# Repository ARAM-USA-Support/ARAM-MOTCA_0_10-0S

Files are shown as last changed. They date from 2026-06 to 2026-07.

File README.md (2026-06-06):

Welcome to the ARAM-MOTCA_0_10-0S documentation mirror.

Read the spec sheet to understand the electrical characteristics of your actuator

View the Quick Start Guide to become familar with how to use your actuator

Example code is provided here, in addition to the code provided within the guide

For those wishing to make their own, they can follow the manufacture guide in the Project File & Technical Data Package.
This is a self contianed zip file, which contains the stl files and assembly guide, along with all the information here.

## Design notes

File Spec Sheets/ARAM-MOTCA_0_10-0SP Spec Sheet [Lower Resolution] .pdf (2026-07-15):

American Robotics Assisted Manufacturing | Rev 6/28/2026

# Metal Orchestra Toggle Actuator

# ARAM-MOTCA_0_11-0SP*

### 0SPG (Pet-g) and 0SPA (PLA) variants

# Spec Sheet

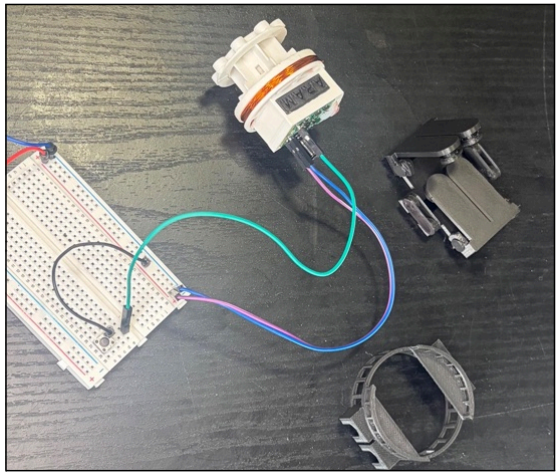
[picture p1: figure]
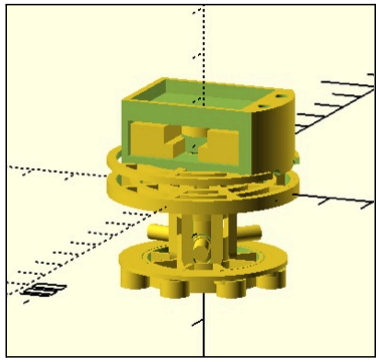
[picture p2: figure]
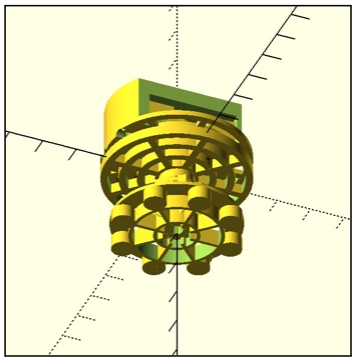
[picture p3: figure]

## Product of American Robotics Assisted Manufacturing www.ARAM-USA.com

## ARAM-MOTCA_0_10-0SP* Spec Sheet

## View further kit usage information & legal information

# Table Of Contents

Overview | 1
Quick Facts - Electrical & Force Characteristics | 2
Pinout Diagram - Basic Operation | 3
Physical And Mechanical Data | 4
Operating Conditions & Limitations | 5

# Overview

This mini actuator is part of the ARAM Metal Orchestra set.

# These are smart actuators utilizing an integrated high efficiency

h-bridge, with simplified control schema requiring only a single pin.

# The actuator integrates a magnetic attaching base to allow these to

attach to any magnetic object.

# These are intended for use as part of the Metal Orchestra kit that allows users to turn household objects into an orchestra. However these have tons of additional applications, including unique I/O

devices, animatronics, smart-home integration and more.

*Please read the usage guide and view legal disclaimers.

# Quick Facts:

# Electrical Characteristics

Continuous Voltage Range | 3.3V - 5V | Over-Voltage* Range | 5.1V - 12V
Average 5V Current Draw | 0.35 - 0.46 Amps | H-Bridge (Driver) Resistance | 0.2 ohms
Total Component Resistance | 11.2 - 13.2 ohms | Solenoid Resistance | 11 - 13 ohms
Input Voltage | 1.8V * (Reduced Efficiency), 3.3V, and 5V

*Actuator may run continuously at or below 5V, above this the Over-Voltage range (5.1V - 12V) is electrically acceptable for the driver to handle, however this will cause the armature to heat up, causing damage over time if not properly cooled.

*1.8 Volts will work for logic, However this has reduced efficiency (greater effective resistance) and will possibly reduce the working life.

# Force Characteristics

| 3.3V | 5V
Strike Time | 50 ms | 20 ms
Force (Average Over Strike) | 0.09 N | 0.22 N
Plunger Weight | 7g
Force of Gravity on Plunger | 0.068 N
Travel Distance | 4.5mm +/- 0.15 mm

### *Force may be limited by magnetic interference

### Material Options: Pet-G, PLA

# Pinout and Basic Usage

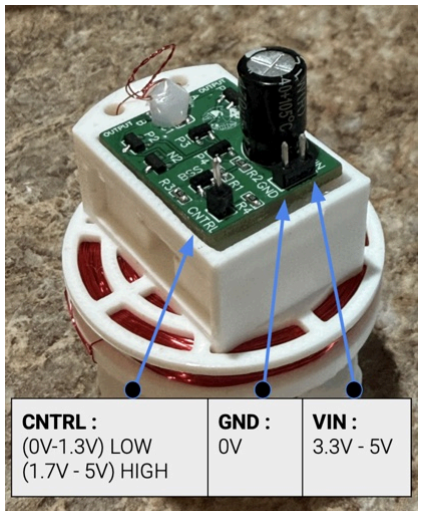
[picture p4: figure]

Pin | Voltage | Additional Comments
VIN | 3.3V to 5V Continuous 5V+ to 12V Pulsed | Incorrectly plugging VIN to 0V may damage your unit
GND | 0V | Incorrectly plugging GND to voltage may damage your unit
CNTRL | (0V - 1.3V) Low (1.7V - 5V) High | (Default) Pulldown to 0V High Signal will cause strike Low Signal will cause retract

# Physical And Mechanical Data

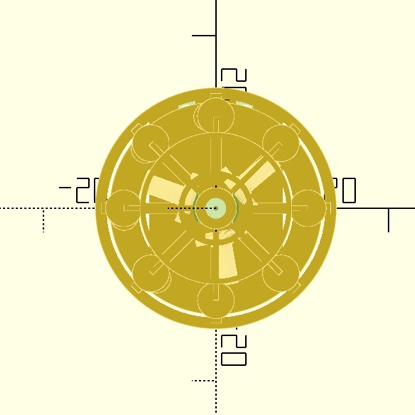
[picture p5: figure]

## Dimensions:

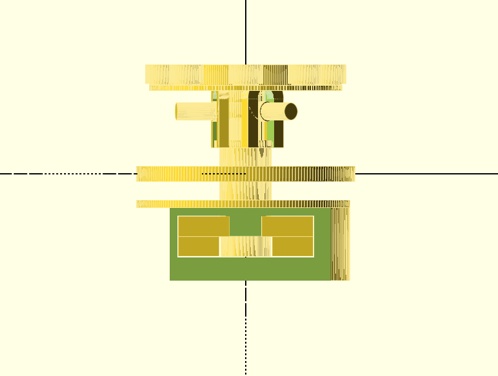
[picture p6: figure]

Height | ~58mm
Diameter | ~40mm

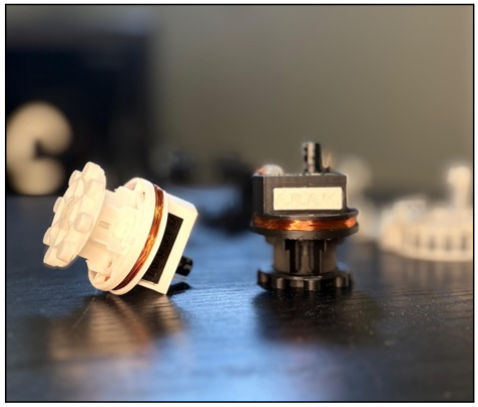
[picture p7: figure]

## Weight: About 42 grams (fully assembled)

## Mounting Options: Magnetic Feet

## Materials: ARAM-MOTCA_0_10-0SPG : Pet-G ARAM-MOTCA_0_10-0SPA : PLA

# Operating Conditions & Limitations

## Maximum Continuous Temperature : 49 degrees celsius *Prolonged temperatures above this range will cause armature housing to deform, especially under weight

## Environmental Notes : Not guaranteed to be dust or water resistant

## Reverse Polarity : failing to follow pin-out and switching the power supply polarity will damage the unit, doing so for a long enough time, with a large

enough power supply can be a potential fire hazard.

## Magnetic Interference : This device produces a magnetic field, be aware of

any damage that may be caused to sensitive electronics, pace makers, etc.

## Troubleshooting: The actuator works most of the time, but when I place it in this specific spot it stops working: The actuator is sensitive to magnetic interference, metal extremely close to the armature tube can cause a loss in power of the device. Either move the

device away from interfering metal, or increase the supply voltage.

## Additional Resources: https://github.com/ARAM-USA-Support/ARAM-MOTCA_0_10-0S (MOTCA-1 Toggle Actuator Github Documentation Mirror) *All documentation is also available at www.ARAM-USA.com

## For any additional troubleshooting or questions please: View Our Website : www.ARAM-USA.com Contact Us At: support@ARAM-USA.com

DISCLAIMER. – ALL PRODUCTS SOLD BY ARAM (AMERICAN ROBOTICS ASSISTED MANUFACTURING) ARE PROVIDED “AS IS” TO THE FULLEST EXTENT PERMITTED BY APPLICABLE LAW, ARAM EXPRESSLY DISCLAIMS ALL WARRANTIES, EXPRESS OR IMPLIED, INCLUDING BUT NOT LIMITED TO THE IMPLIED WARRANTIES OF MERCHANTABILITY, FITNESS FOR A PARTICULAR PURPOSE, AND NON-INFRINGEMENT. ARAM MAKES NO WARRANTY THAT THE PRODUCT WILL MEET YOUR SPECIFIC REQUIREMENTS OR THAT IT WILL OPERATE WITHOUT INTERRUPTION OR ERROR. All units are tested prior to sale; however, ARAM does not warrant that every unit will arrive in working condition. Electrical properties and specifications provided in this document are for reference purposes only. It is the sole responsibility of the user to verify that the specifications provided herein match the electrical characteristics of the unit received. Use of this product outside of stated operating parameters is at the user’s own risk.

Sole Remedy – Replacement Only. ARAM takes no responsibility for any damages caused by the use of our product, whether inside or outside standard operating conditions. In the event of a defect or failure, ARAM’s sole obligation, and your exclusive remedy, shall be the replacement of the defective unit within thirty (30) days of the original purchase date. To qualify for replacement, the buyer must contact ARAM within this period and is responsible for all shipping and handling costs associated with the return and replacement.

Limitation of Liability. TO THE MAXIMUM EXTENT PERMITTED BY APPLICABLE LAW, IN NO EVENT SHALL ARAM BE LIABLE FOR ANY INDIRECT, INCIDENTAL, SPECIAL, CONSEQUENTIAL, OR PUNITIVE DAMAGES OF ANY KIND ARISING OUT OF OR RELATED TO THE USE OR INABILITY TO USE THIS PRODUCT. ARAM’S TOTAL CUMULATIVE LIABILITY TO YOU FOR ANY AND ALL CLAIMS ARISING OUT OF OR RELATED TO THIS PRODUCT SHALL NOT EXCEED THE ORIGINAL PURCHASE PRICE PAID FOR THE SPECIFIC UNIT GIVING RISE TO THE CLAIM. THIS LIMITATION OF LIABILITY SHALL APPLY EVEN IF THE SOLE AND EXCLUSIVE REMEDY PROVIDED HEREIN IS FOUND TO HAVE FAILED OF ITS ESSENTIAL PURPOSE, AND SHALL APPLY WHETHER THE CLAIM IS BASED IN CONTRACT, TORT, STRICT LIABILITY, OR ANY OTHER LEGAL THEORY.

Important Note. Some states, including New York, may have consumer protection laws that limit the enforceability of certain warranty disclaimers. Nothing in this disclaimer is intended to exclude or restrict any rights you may have under applicable state law that cannot be waived by contract.

# Thank you for purchasing an ARAM product

## We would like to thank you for purchasing an ARAM product. We highly value customers like you. If you have any feedback, suggestions, or questions, please reach out to our contact

email. If your unit arrives with any issues please contact us within 30 days for a replacement. We would like to thank you for supporting ARAM, American Robotics Assisted Manufacturing, a 100% American based work force and company.

## Sincerely:

Jack Serlin,

## Founder of American Robotics Assisted Manufacturing

## Contact Email: Support@Aram-usa.com

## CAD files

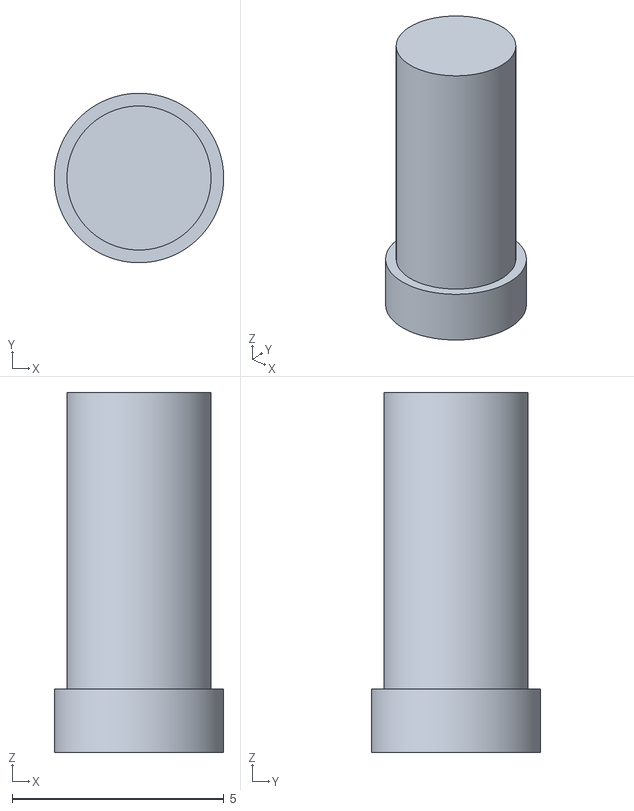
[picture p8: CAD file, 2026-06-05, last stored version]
STL files/MOTCA_1_Plunger_Pin.stl
4.00 x 4.00 x 8.50

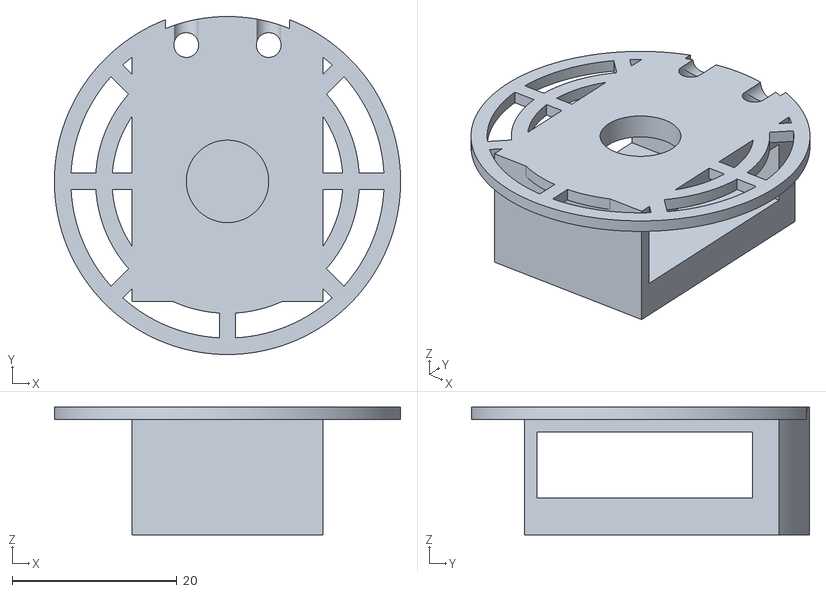
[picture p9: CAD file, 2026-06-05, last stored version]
STL files/MOTCA_1_Armature_Upper.stl
42.0 x 41.0 x 15.5

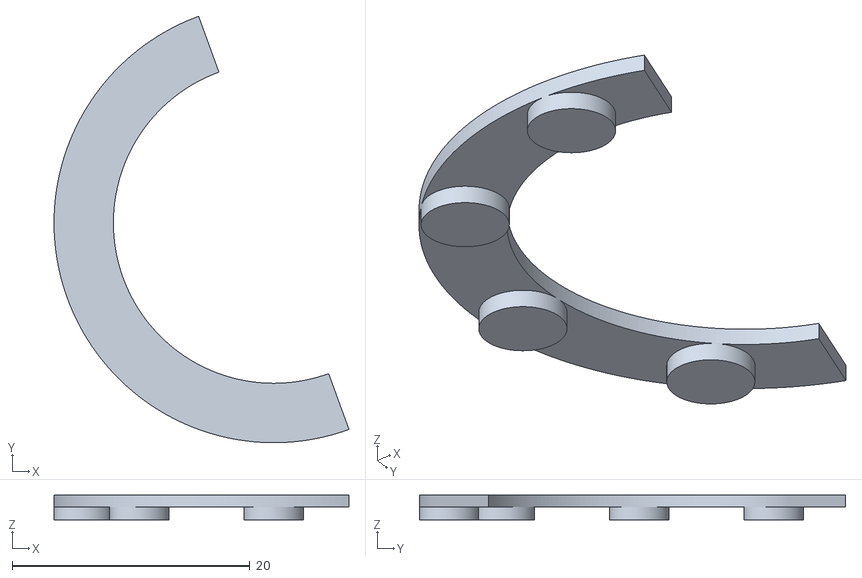
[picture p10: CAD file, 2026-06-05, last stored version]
STL files/MOTCA_1_Armature_Magnetic_Feet_Cover.stl
24.8 x 35.9 x 2.08

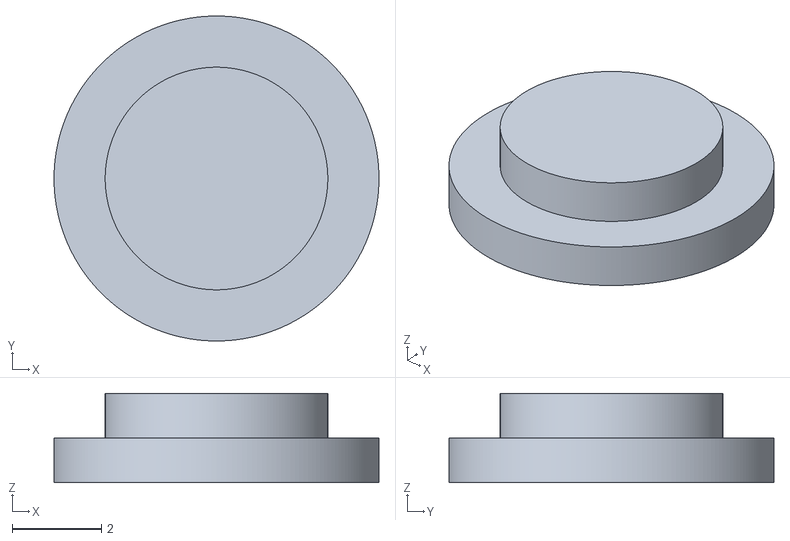
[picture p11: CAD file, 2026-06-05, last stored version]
STL files/MOTCA_1_Plunger_Cap.stl
7.30 x 7.30 x 2.00

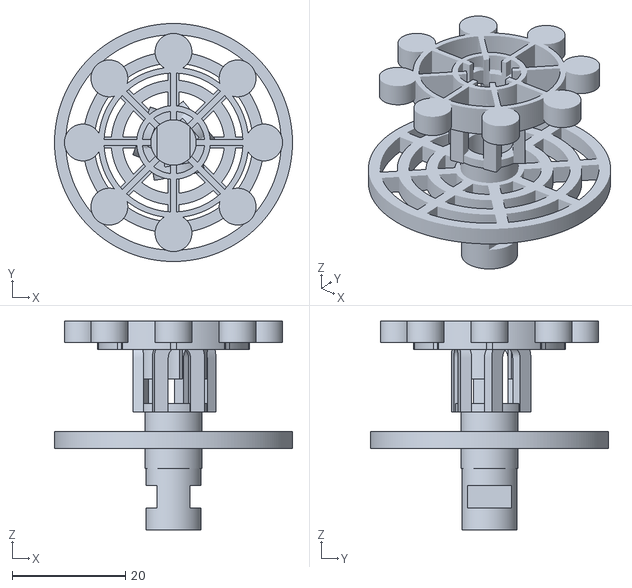
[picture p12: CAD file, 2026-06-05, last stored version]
STL files/MOTCA_1_Armature_Lower.stl
42.0 x 42.0 x 36.8

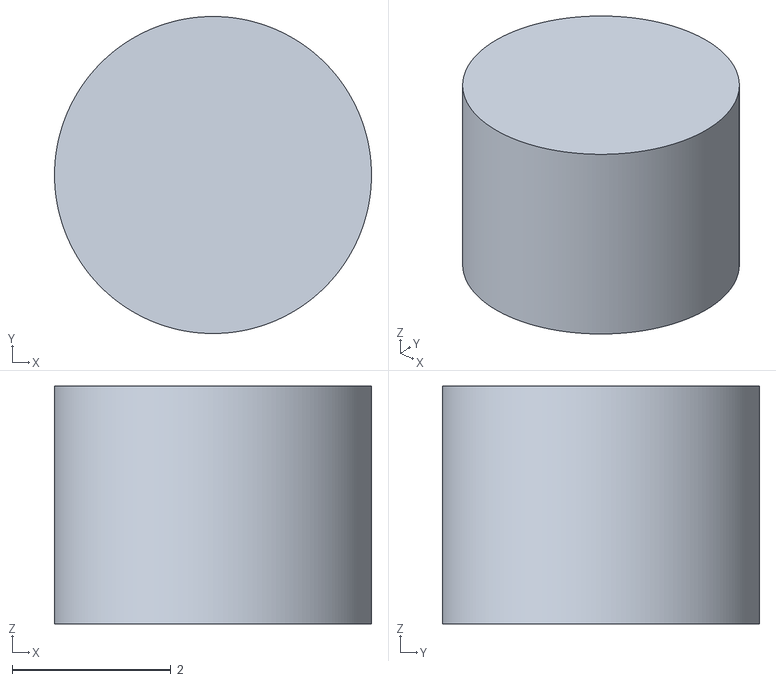
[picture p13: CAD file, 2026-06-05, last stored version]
STL files/bipositional_actuator_v3BasePin.stl
4.00 x 4.00 x 3.00

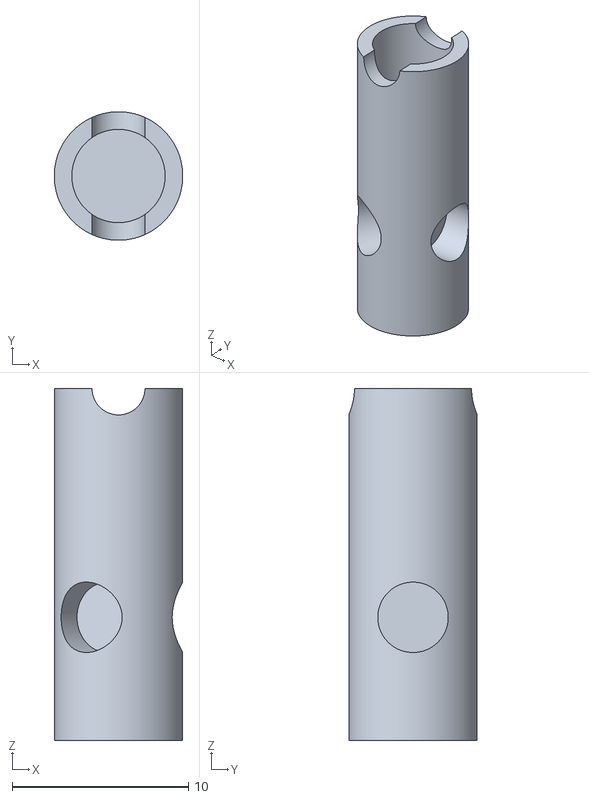
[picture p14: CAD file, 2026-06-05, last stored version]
STL files/MOTCA_1_Plunger.stl
7.30 x 7.30 x 20.0

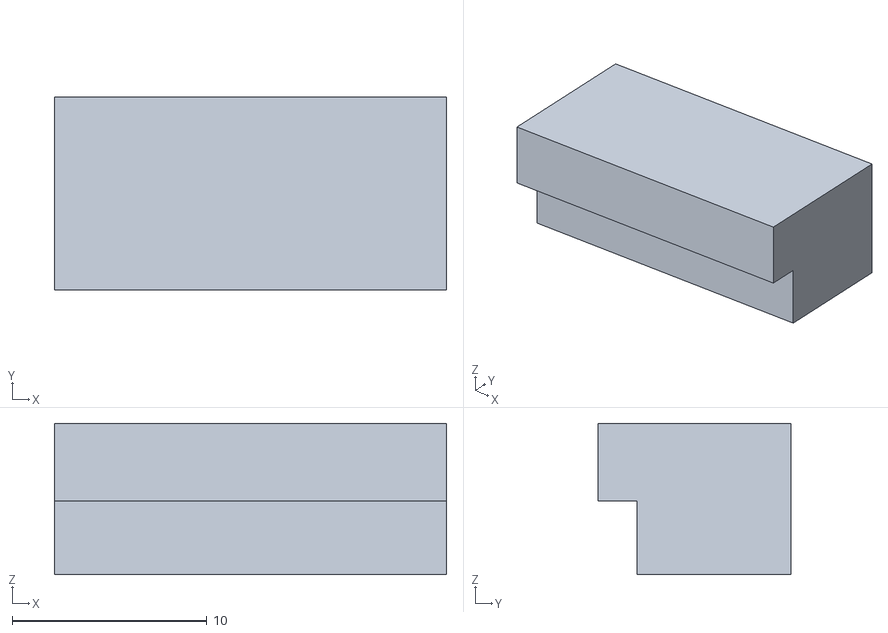
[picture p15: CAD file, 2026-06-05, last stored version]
STL files/MOTCA_1_Armature_Connecting_Insert.stl
20.1 x 9.92 x 7.77

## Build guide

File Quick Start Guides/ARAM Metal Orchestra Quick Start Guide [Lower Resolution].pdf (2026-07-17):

American Robotics Assisted Manufacturing | Rev 6/5/2026

# Metal Orchestra Quick Start Guide

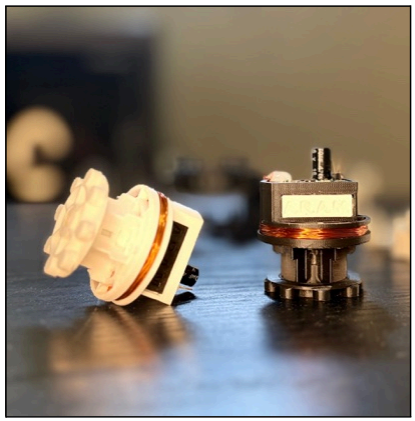
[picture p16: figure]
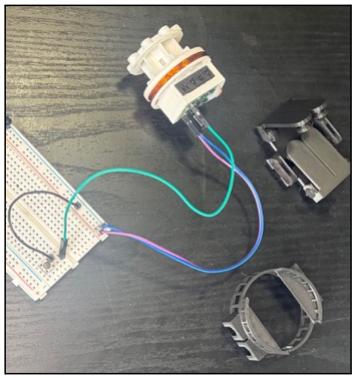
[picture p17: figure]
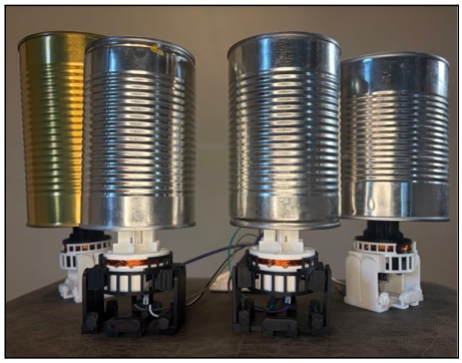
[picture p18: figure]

## Product of American Robotics Assisted Manufacturing www.ARAM-USA.com View further kit usage information & legal information

## ARAM-MOTCA_0_10-0SP Quick Start Guide

# Table Of Contents

Table Of Contents & Introduction | 1
Pinout Diagram | 2
Getting Started With The Arduino Library: Basic Usage | 3 - 5
Making Instruments: Creating Your First Instrument | 6
Making Instruments: Basic Bluetooth MIDI Instrument | 7, 8
Making Instruments: Optimized Bluetooth MIDI instrument | 9 - 11
MIDI Bluetooth Operation: Using With a Mac | 12 - 14
MIDI Bluetooth Operation: Using With a Windows Computer | 15 -19
Tuning: How to Tune Your Actuator to Almost Any Resonator | 20, 21
Conclusion: Thank You, Contact Information, Legal Disclaimer | 22

# Introduction

# Thanks for using ARAM’s Metal Orchestra Kit. Refer to the ARAM-MOTCA_0_10-0SP Spec Sheet and ARAM-MOTCA_0_10-0SP Quick Start Guide for basic usage. This document contains information on how to create and use a Bluetooth MIDI instrument

from the kit.

*Please read the full spec sheet and view legal disclaimers.

# Pinout and Basic Usage


Pin | Voltage | Additional Comments
VIN | 3.3V to 5V Continuous 5V+ to 12V Pulsed | Incorrectly plugging VIN to 0V may damage your unit
GND | 0V | Incorrectly plugging GND to voltage may damage your unit
CNTRL | (0V - 1.3V) Low (1.7V - 5V) High | (Default) Pulldown to 0V High Signal will cause strike Low Signal will cause retract

# Getting Started With The Arduino Library: Basic Usage

## Before Using The Software

## Please make sure the actuator is correctly wired according to the pinout and example

circuits in the ARAM-MOTCA_0_10-0SP Quick Start Guide. Incorrectly switching polarity will damage the unit, (incorrect wiring of Vin and GND).

## When Uploading Code Please Disconnect The Power Supply and the Actuator This avoids drawing too much power from your computer during programming, or additional

issues with ports.

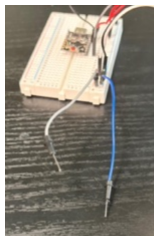
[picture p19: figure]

## Step 1: Disconnect power supply

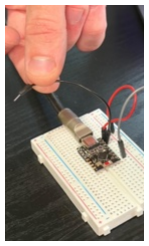
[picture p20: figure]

## Step 2: Disconnect power wire for actuator

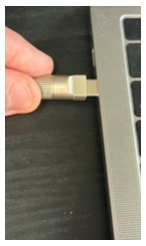
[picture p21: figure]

## Step 3: Connect Esp32 to PC using usb-c

## You’re ready to upload your code!

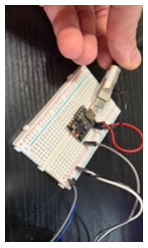
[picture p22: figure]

## Step 4: Disconnect Usb-c when upload is complete

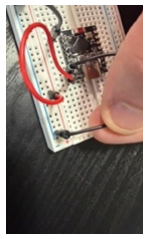
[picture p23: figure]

## Step 5: Reconnect power wire for actuator

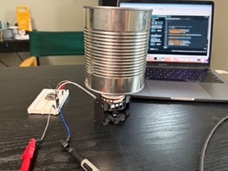
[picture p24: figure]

## Step 6: Reconnect power supply

## It’s ready to be used now!

## When attaching multiple actuators to an instrument ensure the power draw does not exceed the maximum of the power supply. The starter kit comes with a 2 amp power supply, which

can supply enough power for 3 - 4 actuators and an ESP32.

## Using the Software

## First let’s make sure you have the right software, you’ll need the Arduino IDE

## https://www.arduino.cc/en/software/

## Next to use the actuator you’ll need either the ARAM_Toggle_Actuator or the ARAM_Metal_Orchestra library. Search for either by name in the Library Manager

Next you’ll need to import whichever library you downloaded into your program, see any of the

## above code examples, or click more info on either of the libraries to view code examples

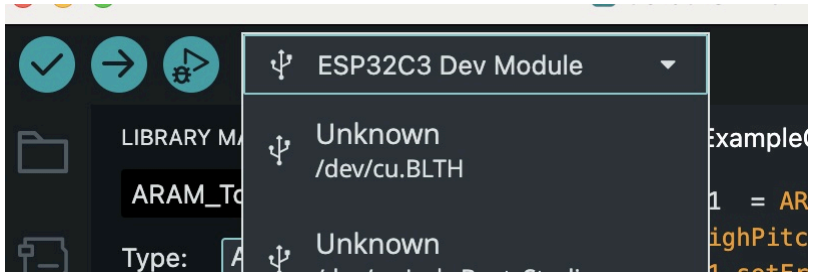
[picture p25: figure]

Before uploading your code, ensure that the correct output is selected.

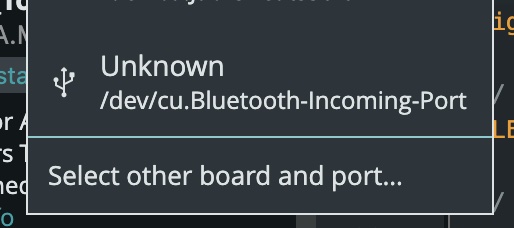
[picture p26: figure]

If you don’t see ESP32C3 Dev Module appear automatically, select the “Select other board and

## port…”

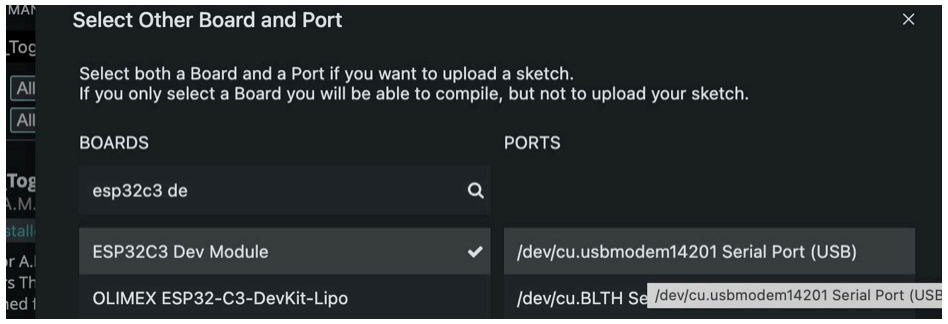
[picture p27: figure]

## Search and Select ESP32C3 Dev Module in the boards section Select the usb Serial Port in the ports section

# Making Instruments: Creating your first instrument

This example code shows creating an instrument, then playing C4.

//import ARAM Metal Orchestra Library
#include <ARAM_Metal_Orchestra.h>

//define what pin we're gonna use
#define CNTRL_PIN_A 1 //change me to your desired cntrl pin A

//declare toggle actuator
ARAM_TOGGLE_ACTUATOR a1;

//declare Instrument
ARAM_METAL_ORCHESTRA_INSTRUMENT instrument;

void setup() {
//initialize toggle actuator with preferred frequency of 800 hz a1 = ARAM_TOGGLE_ACTUATOR(CNTRL_PIN_A, 800);

//initialize toggle actuator with preferred frequency of 800 hz instrument.setInstrumentMode(ARAM_METAL_ORCHESTRA_Resonator);

//add actuator to instrument instrument.addToggleActuator(a1);

//Cause the actuator to play the note C4 instrument.handleNoteOn(0, 60, 127, 0);
//Cause the actuator to stop playing the note C4 //instrument.handleNoteOff(0,60,0,0)
}

void loop() {
//in the loop we must call update on the instrument instrument.update();
}
You can add up to 6 actuators in the same manner, you’ll notice that this time the actuator is declared with a preferred frequency. This is for use with the instrument in choosing which actuator to play specific incoming notes on when the instrument has multiple actuators.

## The instrument will accept basic MIDI noteOn and noteOff commands: instrument.handleNoteOn( channel, frequency, velocity, timestamp)

This is inline with the MIDI note standard.

## For all cases timestamp can be ignored, depending on the specific settings velocity and

channel are generally ignored.

# Making Instruments: Basic Bluetooth MIDI Instrument

## This example code shows creating a bluetooth MIDI instrument

//import ARAM Metal Orchestra Library and Bluetooth MIDI library #include <ARAM_Metal_Orchestra.h>
#include <BLEMidi.h>

//define what pin we're gonna use
#define CNTRL_PIN_A 1 //change me to your desired cntrl pin A

//declare toggle actuator
ARAM_TOGGLE_ACTUATOR a1;

//declare Instrument
ARAM_METAL_ORCHESTRA_INSTRUMENT instrument;

void handleNoteOn(uint8_t channel, uint8_t pitch, uint8_t velocity, uint16_t timestamp) { instrument.handleNoteOn(channel, pitch, velocity, timestamp);
}

void handleNoteOff(uint8_t channel, uint8_t pitch, uint8_t velocity, uint16_t timestamp) { instrument.handleNoteff(channel, pitch, velocity, timestamp);
}

void setup() {
// Initialize a toggle actuator on pin_a, with preferred frequency of 800hz a1 = ARAM_TOGGLE_ACTUATOR(CNTRL_PIN_A,800);

// add toggle actuator to instrument
instrument.addToggleActuator(a1);

// ensure instrument is in standard operating mode instrument.setInstrumentMode(ARAM_METAL_ORCHESTRA_Resonator);

// Initialize the built-in BLEMidiServer object BLEMidiServer.begin("A.R.A.M. Metal Orchestra");

// Register callbacks to the global object BLEMidiServer.setNoteOnCallback(handleNoteOn); BLEMidiServer.setNoteOffCallback(handleNoteOff); }

void loop() {
// call update during the loop on the instrument instrument.update();
}

This is your standard setup for a bluetooth midi instrument, the code is largely the same compared to the basic instrument code. You will however notice: BLEMidiServer.begin This creates a bluetooth midi server Along with BLEMidiServer.setNoteOnCallback BLEMidiServer.setNoteOffCallback These define what functions the server sends the notes to

## Important: this requires the additional download of the BLEMIDI

Install ESP32-BLE-MIDI Library Select nimBLE-Arduino in the library manager: Downgrade to 1.4.3

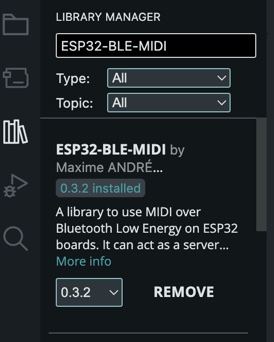
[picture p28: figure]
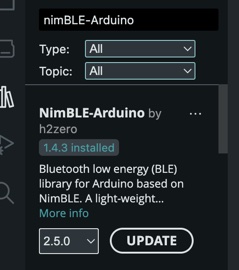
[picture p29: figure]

# Making Instruments: Optimized Bluetooth MIDI Instrument

## This example code shows creating a bluetooth midi instrument with a queue to avoid

blocking.

//import ARAM Metal Orchestra Library and Bluetooth MIDI library
#include <ARAM_Metal_Orchestra.h>

#include <BLEMidi.h>

//define what pin we're gonna use
#define CNTRL_PIN_A 1 //change me to your desired cntrl pin A

//declare toggle actuator
ARAM_TOGGLE_ACTUATOR a1;

//declare Instrument
ARAM_METAL_ORCHESTRA_INSTRUMENT instrument;

//declare MidiEvent object, we use this to represent requested notes struct MidiEvent {
bool isNoteOn;
uint8_t channel;
uint8_t pitch;
uint8_t velocity;
};

//here we actually define the queue in memory, with a maximum size of 16 queued events #define MIDI_QUEUE_SIZE 16
volatile MidiEvent midiQueue[MIDI_QUEUE_SIZE];
volatile uint8_t queueHead = 0;
volatile uint8_t queueTail = 0;

//this functions adds the MidiEvent to the queue
void pushMidiEvent(bool isNoteOn, uint8_t channel, uint8_t pitch, uint8_t velocity) { uint8_t nextHead = (queueHead + 1) % MIDI_QUEUE_SIZE;
if (nextHead != queueTail) {
midiQueue[queueHead].isNoteOn = isNoteOn;
midiQueue[queueHead].channel = channel; midiQueue[queueHead].pitch = pitch; midiQueue[queueHead].velocity = velocity; queueHead = nextHead;
}
}

//these two functions tell the esp32 to add the midi events to the queue when they arrive instead of playing them immediately
void handleNoteOn(uint8_t channel, uint8_t pitch, uint8_t velocity, uint16_t timestamp) { pushMidiEvent(true, channel, pitch, velocity);
}
void handleNoteOff(uint8_t channel, uint8_t pitch, uint8_t velocity, uint16_t timestamp) { pushMidiEvent(false, channel, pitch, velocity);
}

void setup() {
// Initialize a toggle actuator on pin_a, with preferred frequency of 800hz a1 = ARAM_TOGGLE_ACTUATOR(CNTRL_PIN_A,800);

// add toggle actuator to instrument
instrument.addToggleActuator(a1);

// ensure instrument is in standard operating mode instrument.setInstrumentMode(ARAM_METAL_ORCHESTRA_Resonator);

// Initialize the built-in BLEMidiServer object BLEMidiServer.begin("A.R.A.M. Metal Orchestra");

// Register callbacks to the global object BLEMidiServer.setNoteOnCallback(handleNoteOn); BLEMidiServer.setNoteOffCallback(handleNoteOff); }

void loop() {
// call update during the loop on the instrument instrument.update();

// Process the queued MIDI events safely on Core 1 if (queueTail != queueHead) {

//grab midiEvent from queue
MidiEvent event;
event.isNoteOn = midiQueue[queueTail].isNoteOn; event.channel = midiQueue[queueTail].channel; event.pitch = midiQueue[queueTail].pitch; event.velocity = midiQueue[queueTail].velocity; if(event.velocity==0)event.isNoteOn = false;

//delete the midiEvent from the queue so we don't play it twice
queueTail = (queueTail + 1) % MIDI_QUEUE_SIZE;

//this is a helper function that allows you to convert a midi pitch into a frequency (hz) double frequency = midiNoteToFrequency(event.pitch);

//Now we play the note
if (event.isNoteOn) {
highPitchInstrument.handleNoteOn(event.channel, event.pitch, event.velocity, 0); } else {
highPitchInstrument.handleNoteOff(event.channel, event.pitch, event.velocity, 0); }

}

}

## The big change here is the inclusion of a queue. This is important to stop Blocking, when an esp32 receives a bluetooth command it is through something called an interrupt. If the esp32 is still in the middle of an interrupt when a second

bluetooth command comes in, it may skip.

## By adding a queue we make sure the interrupt is as short as possible, and we can actually play the note when the interrupt is over and regular operation has

resumed.

# MIDI Bluetooth Operation: Using With a Mac

## Recommended Software

Software | Audio MIDI Setup | Pocket MIDI | Aria Maestosa
Download | Included on mac | https://apps.apple.com/us/app/pocket-midi/id1260936756?mt=12 (https://apps.apple.com/us/app/pocket-midi/id1260936756?mt=12) | https://ariamaestosa.github.io/ariamaestosa/docs/index.html (https://ariamaestosa.github.io/ariamaestosa/docs/index.html)
Use | Connect to your instrument | Play individual notes | Play sheet music

## Connecting to your instrument

## Open “Audio MIDI Setup”, select the bluetooth icon in the corner

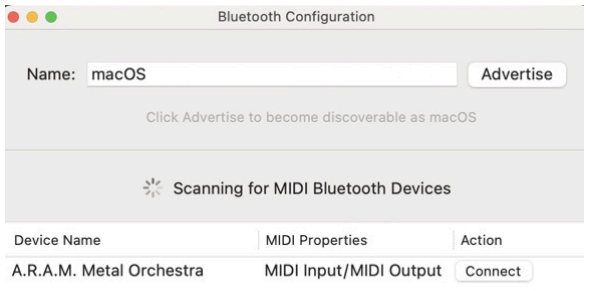
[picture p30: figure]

## In the popup window find the device named “A.R.A.M. Metal Orchestra” and select connect You’re now successfully connected to your Metal Orchestra *If the device does not appear, try resetting the ESP32 with the reset button

## Playing individual notes

## Open Pocket MIDI

## In the OutputPort Select your Metal Orchestra Now press the keys to hear your Orchestra play *If the actuator sounds off for certain notes please see the Tuning section preceding this

## Playing Sheet Music

## Open Aria Maestosa

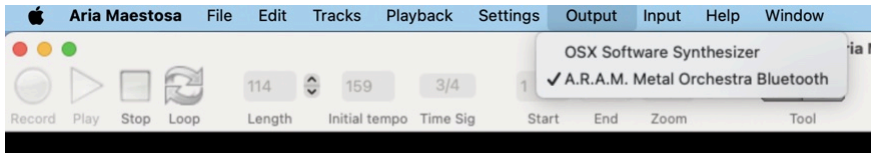
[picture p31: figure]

## Ensure the Metal Orchestra is selected under the Output tab

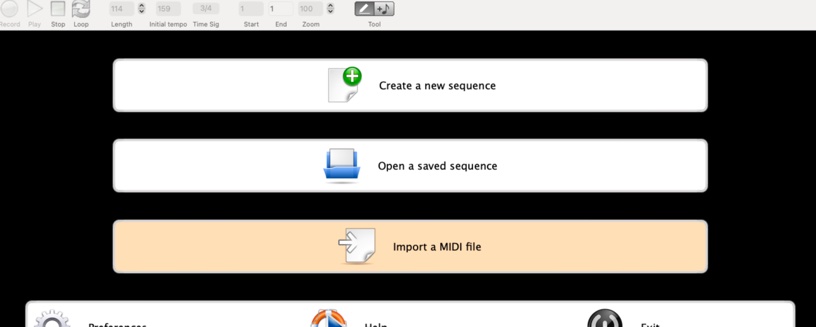
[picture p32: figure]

## Now import any MIDI file you wish to play using the “Import a MIDI file” button

## You can find tons of free sheet music online: Simply search google or visit https://bitmidi.com/ https://github.com/ldrolez/free-midi-chords

# MIDI Bluetooth Operation: Using With a Windows Computer

## Recommended Software

## Downloading Prerequisites

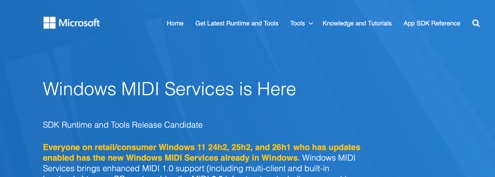
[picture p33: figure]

## Download Windows MIDI Services SDK from the provided link: https://microsoft.github.io/MIDI/get-latest/ (For newer Windows 11 installs this may be already installed)

Software | Windows MIDI services | BLE-MIDI | Pocket MIDI | Aria Maestosa
Download | https://microsoft.github.io/MIDI/get-latest/ (https://microsoft.github.io/MIDI/get-latest/) | https://apps. microsoft.co m/detail/9nv mlzttwwvl?hl =en-US&gl=U S (https://apps.microsoft.com/detail/9nvmlzttwwvl?hl=en-US&gl=US) | https://apps.apple.com/us/app/pocket-midi/id1260936756?mt=12 (https://apps.apple.com/us/app/pocket-midi/id1260936756?mt=12) | https://ariamaestosa.github.io/ariamaestosa/docs/index.html (https://ariamaestosa.github.io/ariamaestosa/docs/index.html)
Use | Drivers for MIDI (May be already installed) | Connect to your instrument | Play individual notes | Play sheet music

## Connecting With BLE MIDI

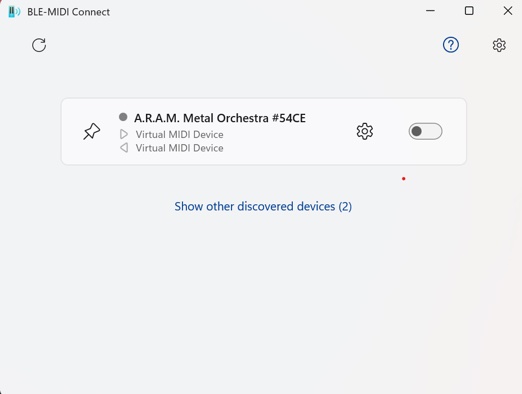
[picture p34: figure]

## In the main window find the device named “A.R.A.M. Metal Orchestra” and select the toggle bar

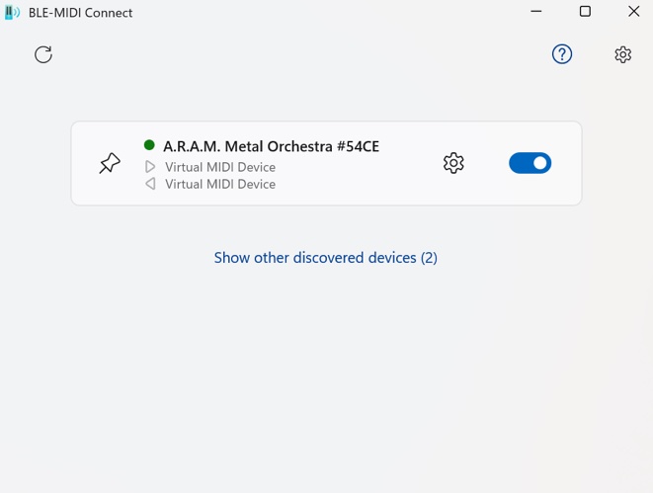
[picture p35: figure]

## You’re now successfully connected to your Metal Orchestra *If the device does not appear, try resetting the ESP32 with the reset button

## Playing Notes With Pocket MIDI

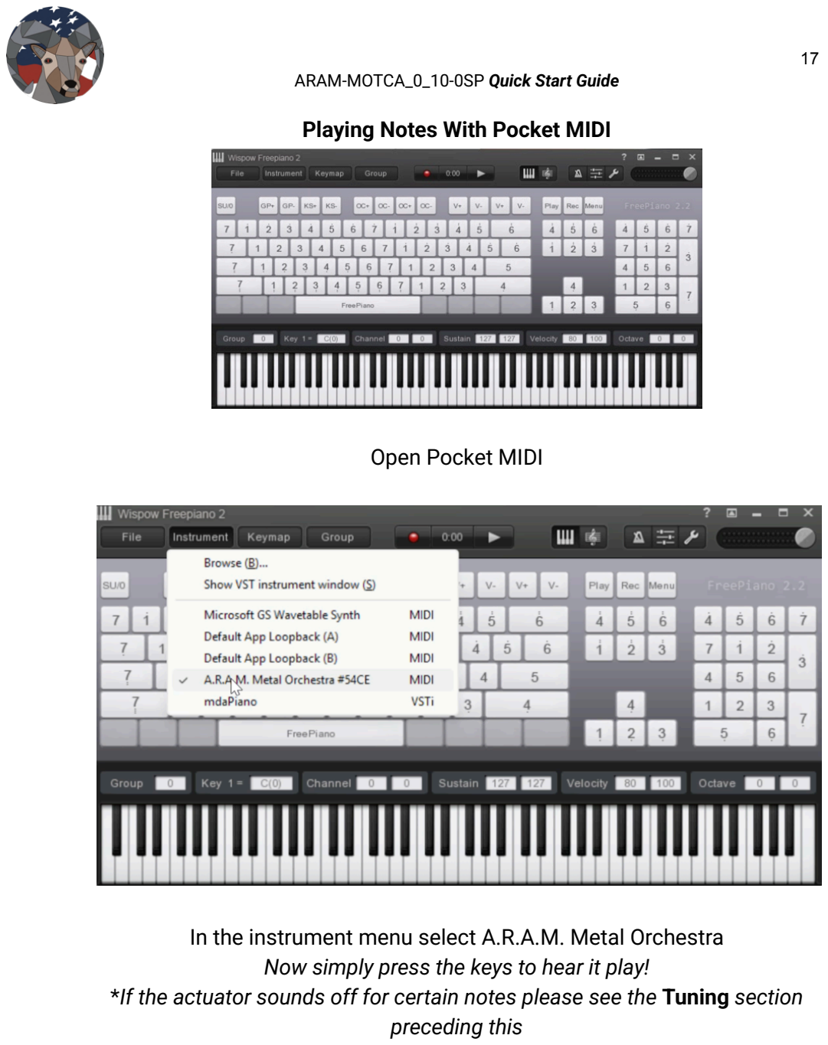
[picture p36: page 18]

## Open Pocket MIDI

## In the instrument menu select A.R.A.M. Metal Orchestra Now simply press the keys to hear it play! *If the actuator sounds off for certain notes please see the Tuning section preceding this

## Playing Sheet Music With Aria Maestosa

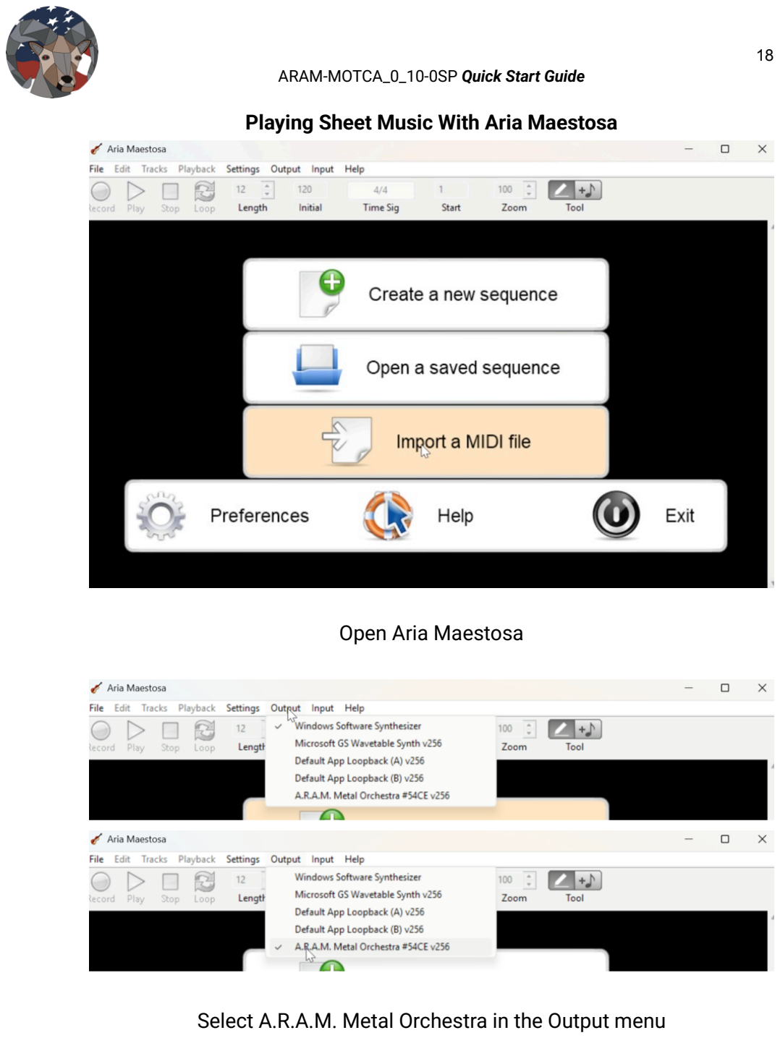
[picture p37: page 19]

## Open Aria Maestosa

## Select A.R.A.M. Metal Orchestra in the Output menu

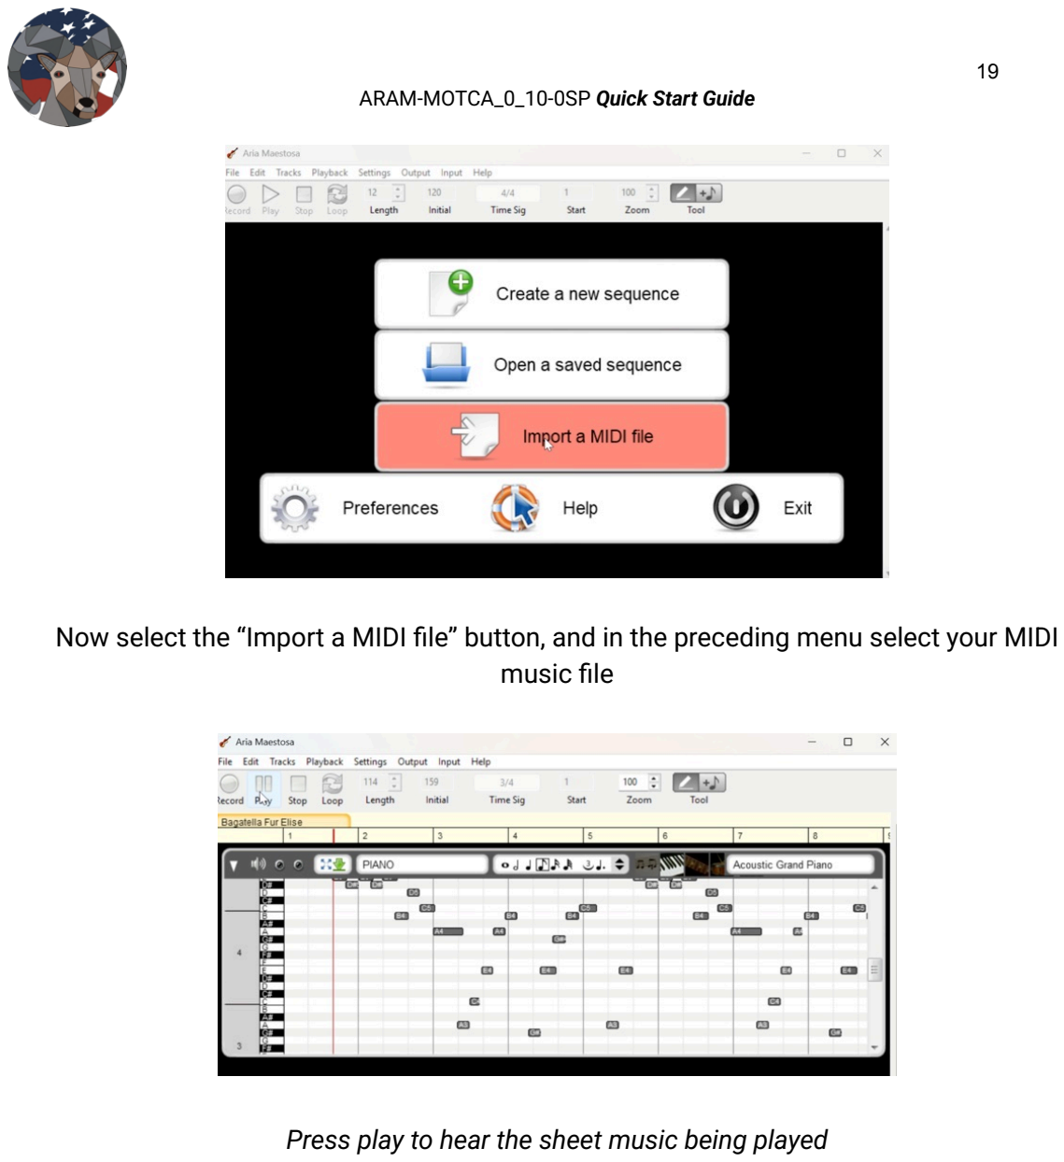
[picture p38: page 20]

## Now select the “Import a MIDI file” button, and in the preceding menu select your MIDI music file

## Press play to hear the sheet music being played

# Tuning: How to Tune Your Actuator to Almost Any Resonator

## When you first setup your actuator and play notes you’ll likely experience the following: High notes sound great Lower notes sound like a rattle rather than music This is because we need to tune your actuator to the resonator

## Software Tuning The standard method is to do this in software

void setup() {
a1 = ARAM_TOGGLE_ACTUATOR(CNTRL_PIN_A,800);

a1.setFrequencyDamping(400, 500, 0.5); a1.setFrequencyDamping(250, 400, 0.85); a1.setFrequencyDamping(200, 250, 0.75); a1.setFrequencyDamping(0, 200, 0.9);

## By using actuator.setFrequencyDamping(minFrequency, maxFrequency, percentage) You can tune to certain frequencies, the percentage is the amount of

damping you want to occur.

## 1 is 100% and the actuator will be completely silent at those frequencies 0 is 0% and the actuator will be loudest at those frequencies

## Increase this at frequencies where you experience the rattling, the rattling is

a result of the actuator and resonator being in too much resonance, causing a massive recoil energy.

## Tuning with a magnet

## Alternatively as you can also tune the actuator to the resonator by placing a

magnet inside the resonator, above the actuator’s plunger.

## This causes the actuator to lose additional energy when it pulls against the

magnet, keeping the resonance from causing recoil.

## By changing the size, strength, and distance of the magnet you can tune the

actuator to different frequencies.

## In theory you can achieve louder notes using this method than software

tuning, because the lost energy is returned on the upwards push.

## Tuning with a soft barrier

## You can also reduce the recoil energy by placing a soft barrier on top of the actuator, in between the magnetic feet and resonator itself. This will absorb the extra energy, eliminating the rattle also

## Recommendation

It’s recommended to use software tuning as this method is the easiest. However tuning with a magnet acts as a fun reinforcement of resonance,

## as you can hear the volume change depending on the magnet’s distance as

you hold above the can, it’s certainly an experiment worth trying.

DISCLAIMER. – ALL PRODUCTS SOLD BY ARAM (AMERICAN ROBOTICS ASSISTED MANUFACTURING) ARE PROVIDED “AS IS” TO THE FULLEST EXTENT PERMITTED BY APPLICABLE LAW, ARAM EXPRESSLY DISCLAIMS ALL WARRANTIES, EXPRESS OR IMPLIED, INCLUDING BUT NOT LIMITED TO THE IMPLIED WARRANTIES OF MERCHANTABILITY, FITNESS FOR A PARTICULAR PURPOSE, AND NON-INFRINGEMENT. ARAM MAKES NO WARRANTY THAT THE PRODUCT WILL MEET YOUR SPECIFIC REQUIREMENTS OR THAT IT WILL OPERATE WITHOUT INTERRUPTION OR ERROR. All units are tested prior to sale; however, ARAM does not warrant that every unit will arrive in working condition. Electrical properties and specifications provided in this document are for reference purposes only. It is the sole responsibility of the user to verify that the specifications provided herein match the electrical characteristics of the unit received. Use of this product outside of stated operating parameters is at the user’s own risk.

Sole Remedy – Replacement Only. ARAM takes no responsibility for any damages caused by the use of our product, whether inside or outside standard operating conditions. In the event of a defect or failure, ARAM’s sole obligation, and your exclusive remedy, shall be the replacement of the defective unit within thirty (30) days of the original purchase date. To qualify for replacement, the buyer must contact ARAM within this period and is responsible for all shipping and handling costs associated with the return and replacement.

Limitation of Liability. TO THE MAXIMUM EXTENT PERMITTED BY APPLICABLE LAW, IN NO EVENT SHALL ARAM BE LIABLE FOR ANY INDIRECT, INCIDENTAL, SPECIAL, CONSEQUENTIAL, OR PUNITIVE DAMAGES OF ANY KIND ARISING OUT OF OR RELATED TO THE USE OR INABILITY TO USE THIS PRODUCT. ARAM’S TOTAL CUMULATIVE LIABILITY TO YOU FOR ANY AND ALL CLAIMS ARISING OUT OF OR RELATED TO THIS PRODUCT SHALL NOT EXCEED THE ORIGINAL PURCHASE PRICE PAID FOR THE SPECIFIC UNIT GIVING RISE TO THE CLAIM. THIS LIMITATION OF LIABILITY SHALL APPLY EVEN IF THE SOLE AND EXCLUSIVE REMEDY PROVIDED HEREIN IS FOUND TO HAVE FAILED OF ITS ESSENTIAL PURPOSE, AND SHALL APPLY WHETHER THE CLAIM IS BASED IN CONTRACT, TORT, STRICT LIABILITY, OR ANY OTHER LEGAL THEORY.

Important Note. Some states, including New York, may have consumer protection laws that limit the enforceability of certain warranty disclaimers. Nothing in this disclaimer is intended to exclude or restrict any rights you may have under applicable state law that cannot be waived by contract.

# Thank you for purchasing an ARAM product

## We would like to thank you for purchasing an ARAM product. We highly value customers like you. If you have any feedback, suggestions, or questions, please reach out to our contact

email. If your unit arrives with any issues please contact us within 30 days for a replacement. We would like to thank you for supporting ARAM, American Robotics Assisted Manufacturing, a 100% American based work force and company.

## Sincerely:

Jack Serlin,

## Founder of American Robotics Assisted Manufacturing

## Contact Email: Support@Aram-usa.com

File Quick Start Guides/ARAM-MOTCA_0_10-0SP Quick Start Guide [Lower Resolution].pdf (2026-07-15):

American Robotics Assisted Manufacturing | Rev 7/15/2026

# Metal Orchestra Toggle Actuator

## ARAM-MOTCA_0_10-0SP*

# Quick Start Guide

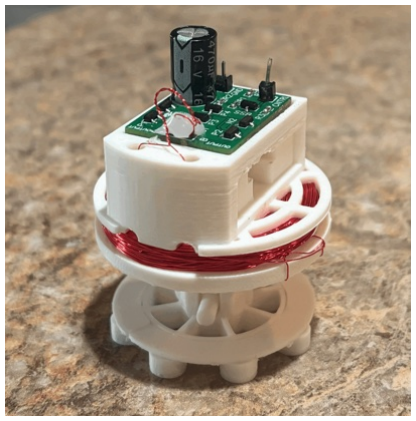
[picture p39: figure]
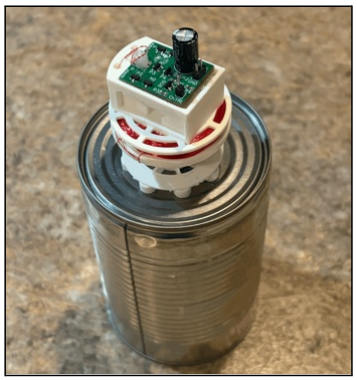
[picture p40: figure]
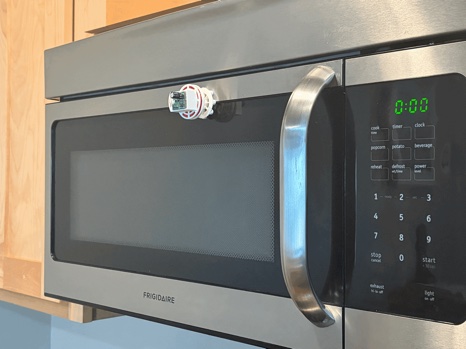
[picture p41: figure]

Product of American Robotics Assisted Manufacturing www.ARAM-USA.com
View further kit usage information & legal information

ARAM-MOTCA_0_10-0SP Quick Start Guide

## Table Of Contents

Table Of Contents & Introduction | 1
Pinout Diagram | 2
Using With A Breadboard: Basic Operation | 3,4
Using With A Breadboard: Basic Operation With Buttons | 5,6
Using With An ESP32/Arduino: Basic Operation | 7,8
Using With An ESP32/Arduino: Actuator Library | 9,10
Using With An ESP32/Arduino: Actuator Library - Using The Actuator | 11
Using With An ESP32/Arduino: Actuator Library - Generating A Beat | 12
Further Uses : Instrument Library, Bluetooth MIDI Instrument | 13
Troubleshooting / Tuning : Tuning troubleshooting, General Troubleshooting | 14 - 16
Conclusion : Thank You, Contact Information, Legal Disclaimer | 17

## Introduction

Thanks for using ARAM’s Metal Orchestra Kit. In here you’ll find everything you need to get started. Including simple usage with buttons, breadboards, and microcontrollers, (ESP32/Arduino). Use this actuator with household metal items to create an orchestra. In the companion “Metal Orchestra Quick Start Guide” view details on using these actuators to create a bluetooth MIDI instrument

*Please read the full spec sheet and view legal disclaimers.

## Pinout and Basic Usage


Pin | Voltage | Additional Comments
VIN | 3.3V to 5V Continuous 5V+ to 12V Pulsed | Incorrectly plugging VIN to 0V may damage your unit
GND | 0V | Incorrectly plugging GND to voltage may damage your unit
CNTRL | (0V - 1.3V) Low (1.7V - 5V) High | (Default) Pulldown to 0V High Signal will cause strike Low Signal will cause retract

## Using With A Breadboard: Basic Operation

Lets confirm the basic operation of your actuator:

You’ll need:

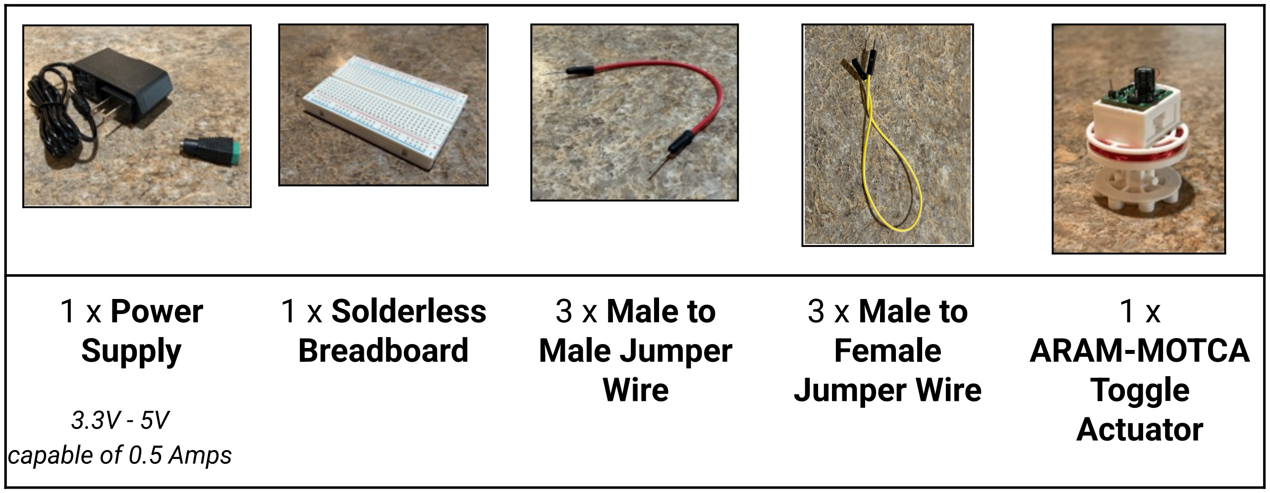
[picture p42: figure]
1 x Power Supply; 3.3V - 5V capable of 0.5 Amps; 1 x Solderless Breadboard; 3 x Male to Male Jumper Wire; 3 x Male to Female Jumper Wire; 1 x ARAM-MOTCA Toggle Actuator

First let’s attach jumpers to the actuator:

- Plug red/white lead into VIN
- Plug blue/black lead into GND
- Plug the remaining color lead into CNTRL

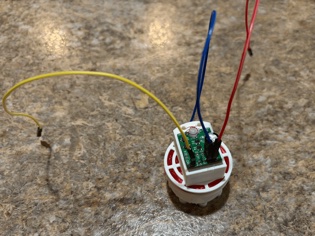
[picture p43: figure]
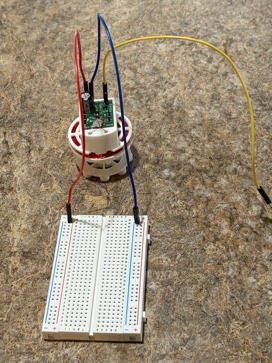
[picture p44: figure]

Now plug the actuator into the breadboard
- Plug the red/white lead into the rail labeled (+) as shown in the image.
- Plug the blue/black lead into the rail labeled (-) as shown in the image.

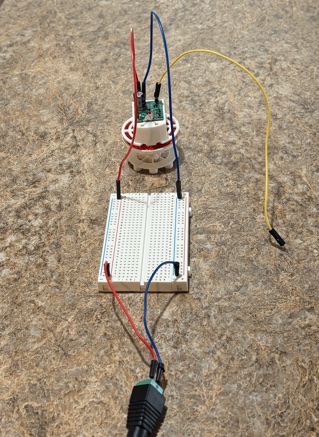
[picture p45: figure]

Next we connect the power supply:
- Connect positive (+) from the power supply to the positive (+) rail of the breadboard
- Connect negative (-) from the power supply to the negative rail of the breadboard
- Before plugging the power supply in: Double check all connections are correct

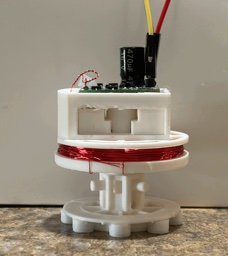
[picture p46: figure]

Your actuator is ready to use!

The actuator has two states:
Strike
Retract

To make the actuator strike, grab that last wire, the CNTRL lead.
- If you plug this lead into (-) the actuator will retract
- If you plug this lead into (+) the actuator will strike

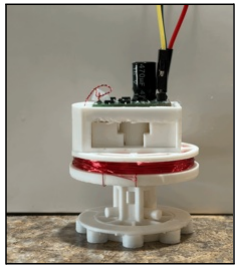
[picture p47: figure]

The CNTRL pin will automatically go to 0V (ie: the negative rail voltage) if you forget to plug it into anything.
Therefore the default behavior for the actuator is to be in the retract position.

## Using With A Breadboard: Basic Operation With Buttons

Let’s make a basic button control board for your actuator:

You’ll need:

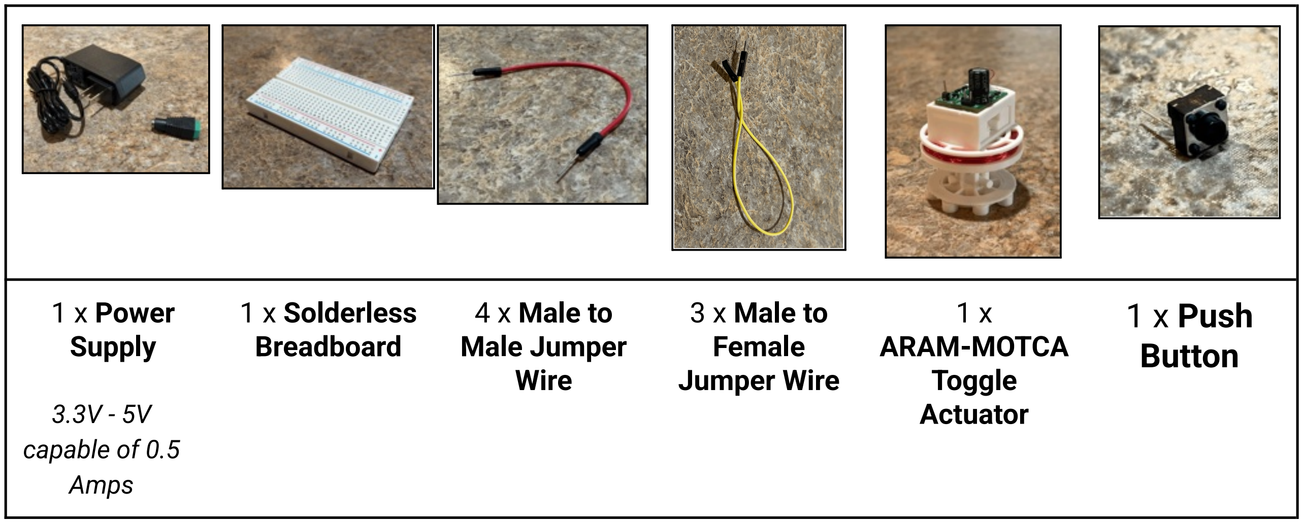
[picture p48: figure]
1 x Power Supply; 3.3V - 5V capable of 0.5 Amps; 1 x Solderless Breadboard; 4 x Male to Male Jumper Wire; 3 x Male to Female Jumper Wire; 1 x ARAM-MOTCA Toggle Actuator; 1 x Push Button
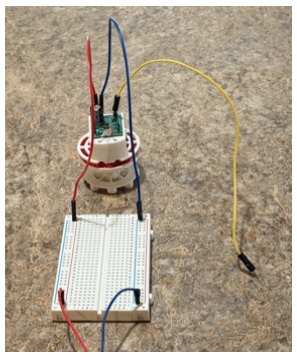
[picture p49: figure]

First wire VIN and GND to the breadboard, along with the power supply like in the previous page.
- Don’t power the supply on yet

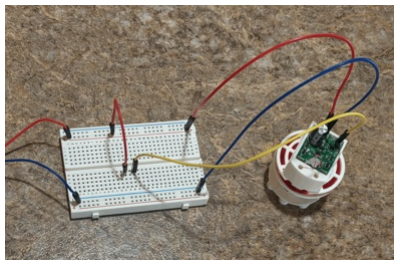
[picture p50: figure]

Now build your button circuit
- Using a jumper connect the positive (+) rail to any rail in the middle of the breadboard

- Connect the CNTRL wire two rails away as shown in the image

Now place a button on the breadboard bridging the two rails.
This completes the button circuit

Always double check your connections before plugging in your power supply

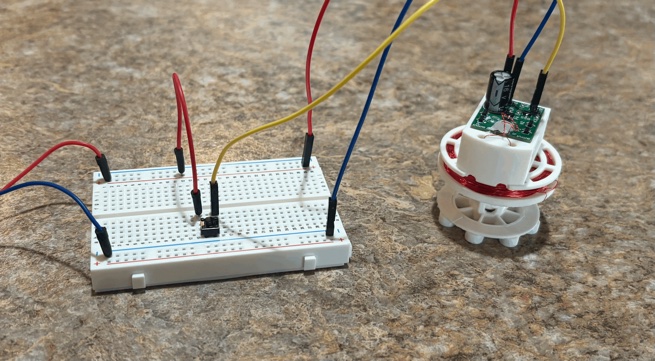
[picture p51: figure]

Simply press the button the strike, and release the button to retract

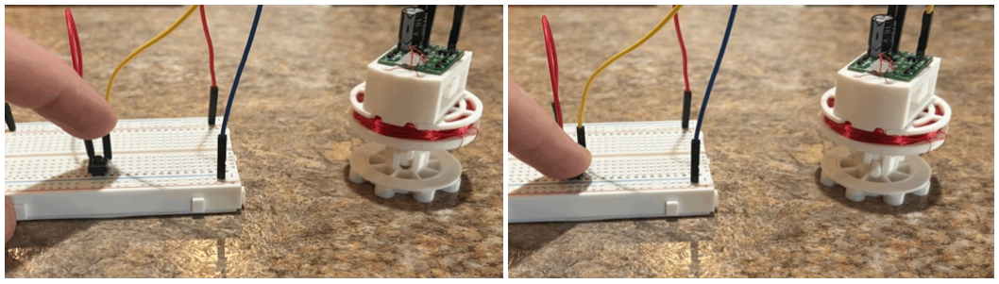
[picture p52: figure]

## Using With An ESP32/Arduino: Basic Operation

This is the basic wiring for all of the ESP32/Arduino Projects shown here

You’ll need:

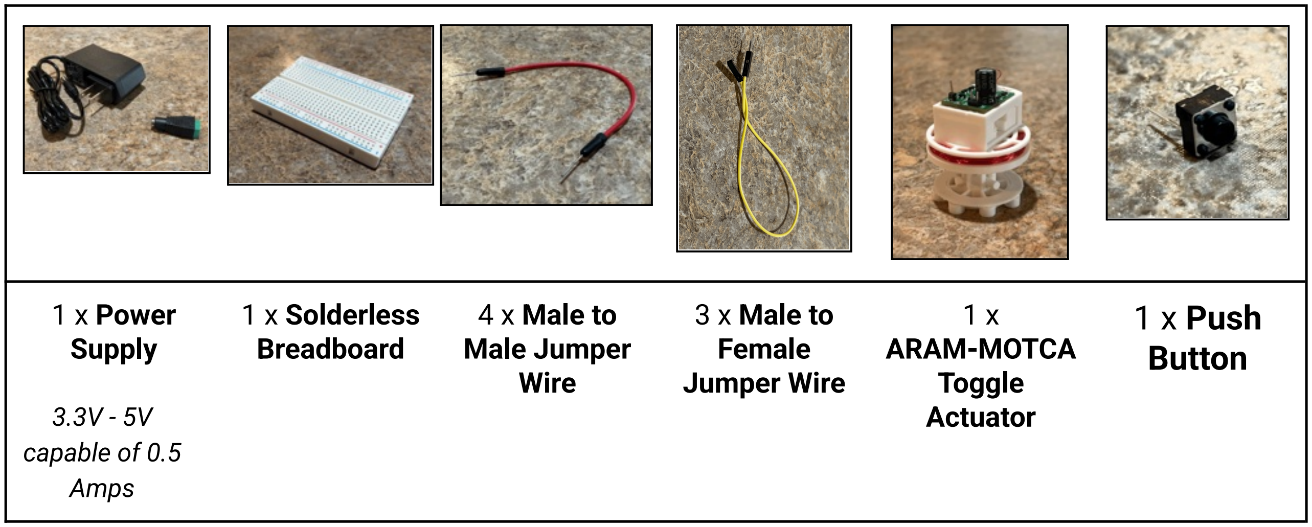
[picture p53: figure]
1 x Power Supply; 3.3V - 5V capable of 0.5 Amps; 1 x Solderless Breadboard; 4 x Male to Male Jumper Wire; 3 x Male to Female Jumper Wire; 1 x ARAM-MOTCA Toggle Actuator; 1 x Push Button
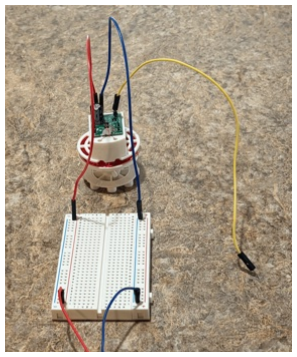
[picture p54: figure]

First wire VIN and GND to the breadboard, along with the power supply like in “Using With A Breadboard: Basic Operation”
- Don’t power the supply on yet

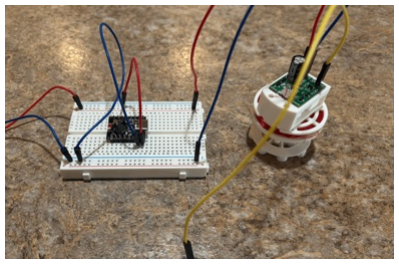
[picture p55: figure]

Now place the ESP32/Arduino In the middle of the breadboard
- Using a jumper connect the positive rail of the breadboard (+), to either VIN (if using 3.3V power supply) or to the 5V pin (If using a 5V power supply).
- Using a jumper connect the negative rail of the breadboard (-), to the GND pin

Now simply connect the CNTRL pin of the actuator to whichever pin of your ESP32/Arduino which you want to control the actuator

Always double check your connections before plugging in your power supply


Now the ESP32/Arduino is ready to use the actuator.

You may strike the actuator by calling: pinWrite(cntrl_pin, HIGH)

You may retract the actuator by calling:
pinWrite(cntrl_pin, LOW)

However the next section covers the implementation of the ARAM_TOGGLE_ACTUATOR library which streamlines the use of these, without needing to call pinWrite directly.

## Using With An ESP32/Arduino: Actuator Library

For ease of use ARAM has released a library compatible with our toggle actuators.

To use the library simply type “ARAM_Toggle_Actuator” into the Arduino IDE library manager, and select the entry by that name.

Getting Started

To import the library into your code use:
#include “ARAM_TOGGLE_ACTUATOR.h”

To declare a new actuator use:
ARAM_TOGGLE_ACTUATOR myActuator;

To initialize the actuator use
myActuator = ARAM_TOGGLE_ACTUATOR( Cntrl_pin );
Or if you intend to use it with the instrument library you must also declare a frequency. myActuator = ARAM_TOGGLE_ACTUATOR( Cntrl_pin , frequency_in_hertz );

(To precisely determine the frequency simply use an audio analyzer app to determine which frequency is loudest when the actuator strikes its target)

Basic Operation

Use the following the make the actuator strike/retract myActuator.strike();
myActuator.retract();

Tune the actuator to the specific resonator attached using
myActuator.setFrequencyTuning( MinFrequency, MaxFrequency, DampingAmount) See Tuning and Troubleshooting for more information on this

Advanced Operation : Update

To use beat, vibrate, or schedule functionality, you must call the following function inside the loop:
myActuator.update();

Advanced Operation : Beats

You can cause the actuator to generate a beat using myActuator.generateBeat(strike_time, beat_timing);

Here strike_time is the amount of time the actuator should be striking for, in milliseconds Here beat_timing is the amount of time between beats, in milliseconds generateBeat(100,1000) -> generates a strike for 100ms every 1 second

Stop the beat using
myActuator.stopBeat();

Advanced Operation : Vibration

You can cause the actuator to vibrate a specific frequency using myActuator.vibrateAt(frequency);

You can stop the vibration using
myActuator.endMovement();

Advanced Operation : Actuator Modes

Putting the actuator into standard actuator mode lets you use all functionality, also the actuator always ends in the retract positon
myActuator.setActuatorMode( ARAM_TOGGLE_ACTUATOR_Actuator );

Putting the actuator into frequency generator mode restrict you to vibrate functionality, also the actuator always ends in the strike positon
myActuator.setActuatorMode( ARAM_TOGGLE_ACTUATOR_Frequency_Generator );

## Using With An ESP32/Arduino: Actuator Library - Using the Actuator

As described in the earlier section, using the actuator with the ARAM_Toggle_Actuator library is incredibly easy. This example code shows declaring an actuator, and then causing it to strike and retract in a repeating motion.

//import ARAM Toggle Actuator Library
#include "ARAM_Toggle_Actuator.h";

//define what pin we're gonna use
#define CNTRL_PIN_A 1 //change me to your desired cntrl pin A

//declare toggle actuator
ARAM_TOGGLE_ACTUATOR a1;

void setup() {

//explicitly set pin to output mode <- may not be necessary gpio_reset_pin(GPIO_NUM_1);

//initialize toggle actuator
a1 = ARAM_TOGGLE_ACTUATOR(CNTRL_PIN_A); }

void loop() {

//make the actuator strike a1.strike();

//wait 75 ms
delay(75);

//retract actuator
a1.retract();

//wait 75 ms
delay(75);
}

## Using With An ESP32/Arduino: Actuator Library -Generating A Beat

This example code shows declaring an actuator, and then causing it to generate a beat. Notice how update() is called in the loop function.

//import ARAM Toggle Actuator Library
#include "ARAM_Toggle_Actuator.h";

//define what pin we're gonna use
#define CNTRL_PIN_A 1 //change me to your desired cntrl pin A

//declare toggle actuator
ARAM_TOGGLE_ACTUATOR a1;

void setup() {
//explicitly set pin to output mode <- may not be necessary gpio_reset_pin(GPIO_NUM_1);

//initialize toggle actuator
a1 = ARAM_TOGGLE_ACTUATOR(CNTRL_PIN_A);

//have the actuator generate a beat a1.generateBeat(100, 500);
}

void loop() {
//in the loop we must call update on each actuator in order to use the beat functionality a1.update();
}

## Further Uses: Instrument Library, and Bluetooth MIDI Instrument

Bluetooth MIDI Instrument : Once you’ve familiarized yourself with the actuator, you can take it to the next level by creating a Bluetooth MIDI instrument. Follow the guide in the companion guide, “Metal Orchestra Quick Start Guide”, to see how this is done.

Instrument Library:
This library is general purpose to turn an array of actuators into a playable instrument. This is what we use for our Bluetooth MIDI Instrument, but it can be used for any other project too. View the companion guide, “Metal Orchestra Quick Start Guide”, to see how this is used.

Additional Resources:
https://github.com/ARAM-USA-Support/ARAM-Metal-Orchestra (Metal Orchestra Github Documentation Mirror) https://github.com/ARAM-USA-Support/ARAM-MOTCA_0_10-0S (MOTCA-1 Toggle Actuator Github Documentation Mirror) *All documentation is also available at www.ARAM-USA.com

For all projects, guides, documents, and questions please: View Our Website : www.ARAM-USA.com Contact Us At: support@ARAM-USA.com

## Tuning and Troubleshooting

I have the kit working, however I found that some notes sound like a loud clacking noise instead of a note: This is normal and we use different tuning methods to achieve a nice clear note on whatever resonator you attach

Software Tuning : (In the arduino IDE)

myActuator.setFrequencyTuning( MinFrequency, MaxFrequency, DampingAmount)

This dampens the actuator between MinFrequency and MaxFrequency by the percentage given in DampingAmount.
Ie:
if damping amount is 1 no sound is produced
If damping amount is 0, no damping occurs, actuator is loudest

Use this to dampen between frequencies where the actuator and resonator create a loud hitting noise instead of a musical note.

Physical Tuning : (Using objects to tune the actuator)

Option 1: Tuning With a Magnet
Placing a magnet opposite to the actuator above the plunger will change the force. You can change the resonances using such a method
The effect will depend on:
The size of the magnet
The strength of the magnet
The distance of the magnet to the actuator You can change any of these variables to see what effect it has on the tuning of the actuator. It is possible to acheive louder sounds through this method

Option 2: Adding a physical buffer
Adding a sheet, paper towel, tissue, or other soft barrier will decrecrease the “recoil” energy at resonant frequencies, although this will in turn reduce volume.

General Troubleshooting :

I’m having issues coding the esp32
First let’s make sure you have the right software, you’ll need the Arduino IDE https://www.arduino.cc/en/software/
Next to use the actuator you’ll need either the ARAM_Toggle_Actuator or the ARAM_Metal_Orchestra library. Search for either by name in the Library Manager


Next you’ll need to import whichever library you downloaded into your program, see any of the above code examples, or click more info on either of the libraries to view code examples


Before uploading your code, ensure that the correct output is selected.


If you don’t see ESP32C3 Dev Module appear automatically, select the “Select other board and port…”


Search and Select ESP32C3 Dev Module in the boards section Select the usb Serial Port in the ports section

DISCLAIMER. – ALL PRODUCTS SOLD BY ARAM (AMERICAN ROBOTICS ASSISTED MANUFACTURING) ARE PROVIDED “AS IS” TO THE FULLEST EXTENT PERMITTED BY APPLICABLE LAW, ARAM EXPRESSLY DISCLAIMS ALL WARRANTIES, EXPRESS OR IMPLIED, INCLUDING BUT NOT LIMITED TO THE IMPLIED WARRANTIES OF MERCHANTABILITY, FITNESS FOR A PARTICULAR PURPOSE, AND NON-INFRINGEMENT. ARAM MAKES NO WARRANTY THAT THE PRODUCT WILL MEET YOUR SPECIFIC REQUIREMENTS OR THAT IT WILL OPERATE WITHOUT INTERRUPTION OR ERROR. All units are tested prior to sale; however, ARAM does not warrant that every unit will arrive in working condition. Electrical properties and specifications provided in this document are for reference purposes only. It is the sole responsibility of the user to verify that the specifications provided herein match the electrical characteristics of the unit received. Use of this product outside of stated operating parameters is at the user’s own risk.

Sole Remedy – Replacement Only. ARAM takes no responsibility for any damages caused by the use of our product, whether inside or outside standard operating conditions. In the event of a defect or failure, ARAM’s sole obligation, and your exclusive remedy, shall be the replacement of the defective unit within thirty (30) days of the original purchase date. To qualify for replacement, the buyer must contact ARAM within this period and is responsible for all shipping and handling costs associated with the return and replacement.

Limitation of Liability. TO THE MAXIMUM EXTENT PERMITTED BY APPLICABLE LAW, IN NO EVENT SHALL ARAM BE LIABLE FOR ANY INDIRECT, INCIDENTAL, SPECIAL, CONSEQUENTIAL, OR PUNITIVE DAMAGES OF ANY KIND ARISING OUT OF OR RELATED TO THE USE OR INABILITY TO USE THIS PRODUCT. ARAM’S TOTAL CUMULATIVE LIABILITY TO YOU FOR ANY AND ALL CLAIMS ARISING OUT OF OR RELATED TO THIS PRODUCT SHALL NOT EXCEED THE ORIGINAL PURCHASE PRICE PAID FOR THE SPECIFIC UNIT GIVING RISE TO THE CLAIM. THIS LIMITATION OF LIABILITY SHALL APPLY EVEN IF THE SOLE AND EXCLUSIVE REMEDY PROVIDED HEREIN IS FOUND TO HAVE FAILED OF ITS ESSENTIAL PURPOSE, AND SHALL APPLY WHETHER THE CLAIM IS BASED IN CONTRACT, TORT, STRICT LIABILITY, OR ANY OTHER LEGAL THEORY.

Important Note. Some states, including New York, may have consumer protection laws that limit the enforceability of certain warranty disclaimers. Nothing in this disclaimer is intended to exclude or restrict any rights you may have under applicable state law that cannot be waived by contract.

## Thank you for purchasing an ARAM product

We would like to thank you for purchasing an ARAM product. We highly value customers like you. If you have any feedback, suggestions, or questions, please reach out to our contact email. If your unit arrives with any issues please contact us within 30 days for a replacement. We would like to thank you for supporting ARAM, American Robotics Assisted Manufacturing, a 100% American based work force and company.

Sincerely:
Jack Serlin,
Founder of American Robotics Assisted Manufacturing

Contact Email:
Support@Aram-usa.com

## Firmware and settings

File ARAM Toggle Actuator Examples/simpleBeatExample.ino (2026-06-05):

//ARAM Toggle Actuator     Example Code                rev: 6/5/2026

/*This example shows the use of four seperate toggle actuators, in the current setup these actuators are on pins 0-3, however you may change this*/

//import ARAM Toggle Actuator Library
#include "ARAM_Toggle_Actuator.h";


//define what pins we're gonna use
#define CNTRL_PIN_A 1     //change me to your desired cntrl pin A
#define CNTRL_PIN_B 2     //change me to your desired cntrl pin B
#define CNTRL_PIN_C 0     //change me to your desired cntrl pin C
#define CNTRL_PIN_D 3     //change me to your desired cntrl pin D


//declare 4 toggle actuators
ARAM_TOGGLE_ACTUATOR a1;
ARAM_TOGGLE_ACTUATOR a2;
ARAM_TOGGLE_ACTUATOR a3;
ARAM_TOGGLE_ACTUATOR a4;



void setup() {

  //explicily set pins to output mode <- may not be nessesary
  gpio_reset_pin(GPIO_NUM_0);
  gpio_reset_pin(GPIO_NUM_3);
  gpio_reset_pin(GPIO_NUM_4);
  gpio_reset_pin(GPIO_NUM_5);
  pinMode(0, OUTPUT);
  pinMode(3, OUTPUT);
  pinMode(4, OUTPUT);
  pinMode(5, OUTPUT);


  //initialize 4 toggle actuators
  a1  = ARAM_TOGGLE_ACTUATOR(CNTRL_PIN_A);
  a2  = ARAM_TOGGLE_ACTUATOR(CNTRL_PIN_B);
  a3  = ARAM_TOGGLE_ACTUATOR(CNTRL_PIN_C);
  a4  = ARAM_TOGGLE_ACTUATOR(CNTRL_PIN_D);

  //have each actuator generate a seperate beat
  a1.generateBeat(100, 500);
  a2.generateBeat(75, 750);
  a3.generateBeat(100, 1250);
  a4.generateBeat(75, 1750);
}

void loop() {
  //in the loop we must call update on each actuator in order to use the beat functionality
  a1.update();
  a2.update();
  a3.update();
  a4.update();
}

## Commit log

2026-06-05 Initial Documentation Upload
    [MOTCA_1_Armature_Connecting_Insert.stl, MOTCA_1_Armature_Lower.stl, MOTCA_1_Armature_Magnetic_Feet_Cover.stl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]
2026-06-06 Moved STL files into technical data package
    [MOTCA_1_Armature_Connecting_Insert.stl, MOTCA_1_Armature_Lower.stl, MOTCA_1_Armature_Magnetic_Feet_Cover.stl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]
